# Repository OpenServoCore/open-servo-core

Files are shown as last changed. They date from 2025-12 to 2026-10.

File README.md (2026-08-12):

<p align="center">
  <picture>
    <source media="(prefers-color-scheme: dark)" srcset="docs/logo-dark.svg">
    OpenServoCore logo
  </picture>
</p>

# OpenServoCore

> An open platform for turning cheap servos into smart actuators.

OpenServoCore (OSC) is open hardware and firmware that drops a CH32V006 control board into a $2-3 cloned hobby servo (SG90 and friends) and turns it into a Dynamixel-class smart actuator with position feedback, current sensing, bus addressing, and programmability. The bus speaks the **osc-native protocol**, a break-framed wire protocol designed to run whole on sub-$0.20 MCUs ([design writeup](https://aaronqian.com/log/2026-08-08-servo-protocol-stream-processing/)).

The thesis is the price point. At mass-production volume, an OSC swap board should add **no more than ~$1 to the BOM** of a cloned servo. That is cheap enough that upgrading every servo in a robot to smart becomes the default instead of a premium decision.

If you are here for a board, jump to [Boards](#boards). The firmware and its progress are in [Firmware](#firmware), and the design writeups are in [Reading](#reading).

## Status

**In active development. Nothing here is shippable yet.** What exists today:

- The **OSC Dev CH32** dev board is validated (Rev B) and you can order one.
- The firmware's protocol and bus transport are implemented and bench-proven on real silicon. Control loops are next.
- **[tinyboot](https://github.com/OpenServoCore/tinyboot)**, the OSC bootloader, has shipped v0.4.0 as its own repo.

The servo swap board (the one that goes inside a servo) is designed but not spun yet.

## Boards

**OSC Dev CH32** (`hardware/boards/osc-dev-v006/`) is the firmware development platform. It accepts any gutted hobby servo, takes power from USB-C, 1S-2S LiPo, or a WCH-LinkE, and fans out every rail and signal to edge test points. Rev B is validated. The [board README](hardware/boards/osc-dev-v006/README.md) has full schematics, pinouts, jumper behaviour, and bringup notes.

Want one? The full KiCad design files live in `hardware/boards/osc-dev-v006/`, ready to send to the board house of your choice.

There is also an experimental BLDC variant (`osc-dev-m007`) in the tree. It is unvalidated, so don't fab it.

## Firmware

The firmware is written in Rust and lives in `firmware/`. It is organized as chip-agnostic library crates (protocol, drivers, control table, discrete-event integration tests), a CH32 chip crate, and board binaries. The chip-agnostic layers compile and unit-test on a desktop with no hardware attached, and a discrete-event simulation runs the production crates ([the architecture writeup](https://aaronqian.com/log/2026-08-01-chip-agnostic-architecture-bare-metal-rust/) covers how).

What works today is the osc-native protocol and the servo bus transport. On the bench that means 0.5-3 Mbaud multi-servo status chains, ~30 µs ping turnaround at 1 Mbaud, and hardware CRC in both directions. The register-table conventions (flat control table, staged writes, alert semantics) will feel familiar if you have used Dynamixel. Control loops, persistence, and safety features are in progress, and build instructions will appear as the firmware matures.

The bootloader, [tinyboot](https://github.com/OpenServoCore/tinyboot), is a separate repo. It is part of the OSC firmware stack but versioned and released independently, and it supports more chips than the OSC boards on purpose (V003 / V00x / V103).

## Reading

The deep-dive writeups live on the blog:

- **[Stream processing on the wire](https://aaronqian.com/log/2026-08-08-servo-protocol-stream-processing/)**: the osc-native protocol design, and how the servo replies in tens of microseconds on a $0.16 chip.
- **[A chip-agnostic architecture for bare-metal embedded Rust](https://aaronqian.com/log/2026-08-01-chip-agnostic-architecture-bare-metal-rust/)**: the full firmware architecture, layer by layer, with code.
- **[Using the SPI peripheral as a DMA-fed CRC engine](https://aaronqian.com/log/2026-07-25-spi-as-dma-crc-engine/)**: hardware CRC on a chip with no CRC peripheral.
- **[HSI trim: calibrating a crystalless MCU over the bus](https://aaronqian.com/log/2026-07-18-hsi-trim-crystalless-mcu/)**: fleet clock calibration with nothing but the bus wire.
- **[Dynamixel 2.0 servo side: RX timing](https://aaronqian.com/log/2026-07-04-dynamixel-servo-side-rx-timing/)** and **[Fast Sync/Bulk Read](https://aaronqian.com/log/2026-07-11-dynamixel-servo-side-fast-sync-bulk-read/)**: the reference pair if you are building a Dynamixel-compatible device.

There is also one design doc in the repo worth reading. [Control theory](docs/control-theory.md) lays out the control design for the servo, with the cascaded loops, the estimators, and the sensing tiers. It is the plan, written ahead of the implementation, and it is not implemented yet.

## AI Use

I use AI heavily in this project. Claude (Fable 5, Opus 5, and earlier models) does a lot of the code generation and most of the document drafting, including parts of this README.

That does not make this vibe-coded. I review every line before it lands, and the result has to survive checks that don't care how the code was written. CI builds and tests every crate and cross-builds every board image. A discrete-event simulation runs the production crates and caught over a dozen real bugs before they reached silicon. The transport numbers above were measured on the bench. And this project was not built in one prompt. The history spans multiple years and many revisions of both the hardware and the firmware.

The documentation is more uneven than the code, and even this README could be easier to consume. That will improve, but working firmware comes first.

## Contributing

This is early. The most useful thing right now is **following along and asking questions** rather than opening PRs.

- **Discussions:** [github.com/OpenServoCore/open-servo-core/discussions](https://github.com/OpenServoCore/open-servo-core/discussions) is where design questions, ideas, and "is this on the roadmap?" go.
- **Build journey:** posts at [aaronqian.com](https://aaronqian.com) document the design decisions, dead ends, and what shipped each week.
- **Issues:** open ones are scoped to specific work. For now, contributor scope is small.

## License

OSC is fully open source.

- **Firmware**: [MIT](LICENSE-MIT) **OR** [Apache-2.0](LICENSE-APACHE), at your option (Rust ecosystem convention).
- **Hardware** (schematics, layouts, board files): [CERN-OHL-P v2.0](LICENSE-HARDWARE).

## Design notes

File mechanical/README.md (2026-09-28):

# mechanical

Parametric CAD for OSC mechanical parts, written in
[build123d](https://github.com/gumyr/build123d) (Python, OCCT kernel).
One folder per project; each project writes its printable outputs
(STEP/STL/SVG/preview PNGs) to its own `build/` (gitignored).

- `sg90/` - SG90 servo modeling: motor, gears, pot, case, light fence.
  Measurements go into `sg90/measurements.py` with provenance; geometry
  is derived from them. One part per module; `build()` returns the
  solid.
- `mg90/` - MG90 clone facts, no geometry yet: `mg90/measurements.py`
  holds the counted gear train with the same provenance tags.
- `encbench/` - bench encoder rig for the ITR1204 coupon
  (hardware/boards/encoder-board): base, sled, clamp, discs, shims,
  paper patterns. Parametric over motor dims (imports
  `sg90.measurements`) and quadrature-phase presets.
- `carrier/` - tier-2 encoder carrier: printed pot replacement (stator
  body with coupon shelf + magnet cup rotor) around purchased 1.4mm rod
  and brass tube stock; imports `sg90.measurements`, dims pending the
  donor measurement session.
- `stenciljig/` - solder-paste stencil jig, build123d implementation
  of the mechanism from bobstay's parametric jig
  (printables.com/model/1209372, credited with thanks). Heat-set
  inserts swapped for captive M3 nuts, plate screws top-driven via
  under-base nut bars. One part per file, shared spec in
  `common.py`, mating cavities offset from the owning part's
  profile; every part exports pre-oriented and support-free (all
  internal ceilings are 45-degree tents, hoppers or cones). Two
  stacking parts: the jig stands on screw-on feet next to an open
  tote (`box.py`) standing on four of the same feet, holding the
  thickness adapters, low-profile standing-wedge squeegees, stencil
  sheets and spares; for transport the jig stacks onto the box as
  its lid - the rear feet's hook noses latch the box wall and two
  printed quarter-turn cam knobs seat under the box's descending
  ceiling tents to draw it down tight, no hardware in the joint.
  TPU desk pads snap into the feet's through bores (one pad and one
  foot model everywhere).
- `render.py` - shared headless STL preview.

## Setup

```sh
python3 -m venv .venv
.venv/bin/pip install -r requirements.txt
```

## Build

Run from `mechanical/`:

```sh
.venv/bin/python -m sg90.motor    # one part -> sg90/build/
.venv/bin/python -m encbench      # all rig parts -> encbench/build/
.venv/bin/python -m render sg90/build/sg90_motor.stl   # preview PNG
```

Stable STEPs consumed by KiCad get copied to `hardware/shared.3dshapes/`
deliberately, not by the build.

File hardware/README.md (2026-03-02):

# KiCad Component Management

## Component Linkage System

### Directory Structure

```
hardware/
├── shared.kicad_sym        # Symbol library
├── shared.pretty/           # Footprint library
├── shared.3dshapes/         # 3D models
├── templates/jlc4l_1v6mm/   # Template project (canonical reference)
└── boards/*/                # Board projects
```

### Linkage Patterns

#### 1. Project → Libraries

Projects link to shared libraries via `sym-lib-table` and `fp-lib-table`:

- Symbol library: `${KIPRJMOD}/../../shared.kicad_sym`
- Footprint library: `${KIPRJMOD}/../../shared.pretty`

#### 2. Symbol → Footprint

Symbols in `shared.kicad_sym` reference footprints using library prefix:

- Format: `"shared:FOOTPRINT_NAME"`
- Example: `"shared:UQFN-20_L3.0-W3.0-P0.40-BL-EP1.7"`

#### 3. Footprint → 3D Model

Footprints in `shared.pretty/` reference 3D models using relative paths:

- Format: `${KIPRJMOD}/../../shared.3dshapes/MODEL_NAME.wrl`
- Example: `${KIPRJMOD}/../../shared.3dshapes/UQFN-20_L3.0-W3.0-P0.40-BL-EP1.7.wrl`

## Component Acquisition Strategy

1. Navigate to a board or template directory:

   ```bash
   cd hardware/templates/jlc4l_1v6mm
   ```

2. Download component:

   ```bash
   easyeda2kicad --full --lcsc_id <LCSC_ID> --output ../../shared --overwrite --project-relative
   ```

3. Fix 3D model paths in footprint files:
   - Find: `${KIPRJMOD}././shared.3dshapes`
   - Replace: `${KIPRJMOD}/../../shared.3dshapes`

4. In `shared.kicad_sym`, rename the `LCSC Part` property to `LCSC` on the downloaded symbol.

## Post-Import Checklist

- [ ] Symbol has correct footprint reference (`"shared:FOOTPRINT_NAME"`)
- [ ] Footprint has correct 3D model path (`${KIPRJMOD}/../../shared.3dshapes/...`)
- [ ] Pin types are correctly set: power_in (VCC/GND), input (control/data in), output (data out), passive (connectors) - NO "unspecified" pins allowed
- [ ] 3D model displays correctly in KiCad 3D viewer
- [ ] Symbol uses `LCSC` property (not `LCSC Part`) for the part number
- [ ] Component source documented (LCSC part number)

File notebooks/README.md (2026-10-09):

# notebooks

This folder is where I look at real data from the servo rig. The firmware
streams raw ADC samples at the full 20 kHz control rate, the captures get
checked in under `telemetry/`, and the notebooks load them, plot them, and
check the control math against what the hardware actually did.

These notebooks are for understanding and for writeups, not for CI. They are
committed with their outputs baked in, so they read as documentation straight
from GitHub.

## Setup

You will need [uv](https://docs.astral.sh/uv/). Then:

```
cd notebooks
uv sync
uv run jupyter lab
```

`uv sync` creates a `.venv` and installs numpy, scipy, pandas, matplotlib, and
jupyterlab. Python is pinned to 3.12 in `.python-version`, and uv will fetch it
for you if you don't have it.

`uv run pytest` runs the tests under `tests/`, which check the parts of
`oscnb` that can be checked offline against data with a known answer.

## Telemetry

The captures live under `telemetry/`, one folder per dataset (one servo or
static load, on one board, on one supply), then one folder per experiment, then
one folder per capture:

```
telemetry/
  sg90-a__dev-v006-D__2s/
    dataset.toml
    grid/
      capture-1/
        meta.json
        sweep.csv.gz
```

Every recording is raw ADC counts straight off the wire, with a per-sample
tick counter, so missing samples are provable from the data itself. The
constants that turn counts into volts and amps live in `oscnb/boards.py` (the
measurement chain) and `oscnb/servos.py` (the thing measured). Each
recording's `meta.json` carries the board's parts in a `sense` block, and the
loader picks the board from it and refuses a capture that does not match.

## The notebooks

Each notebook states what it measures, how, and what is still open at its end.
01 to 08 read an SG90 on board D, the hand-reworked development board before
rev 2A; 09 reads an MG90 on board D; 10 on read rev 2A, with board D alongside
where a comparison needs it.

- `01-bridge-states`: what each ADC sample means in each H-bridge state and
  decay mode, and when it is valid.
- `02-electrical`: winding resistance and brush drop as a two-parameter line,
  the winding inductance, and the burst fit's R-V0 ridge.
- `03-back-emf`: the back-EMF constant by three routes, and ripple speed plus
  coast back-EMF as a speed that needs no pot.
- `04-friction`: Coulomb and viscous friction from coast deceleration and
  steady current, and breakaway.
- `05-inertia`: rotor inertia from the rise curve, cross-checked by coast.
- `06-gear-train`: the ripple tachometer, motor angle against the pot, gear
  play and slip signatures.
- `08-velocity-observer`: rest noise per channel and its structure, then
  back-EMF, pot derivative and ripple as speed estimates, and how the observer
  combines them.
- `09-pot-linearization`: the ripple-referenced position table and degrees
  from counted teeth.
- `10-sense-chain-boards`: capture integrity, and the sense chain graded
  against a meter on a resistor grid, board against board. Then the current
  reading on rev 2A's final amplifier network, on a stalled MG90 and a 15.3 ohm
  resistor, and the settle gain it needs.
- `11-back-emf-on-rev-2a`: the low-duty back-EMF over-read, re-scored on rev 2A.
- `12-pot-table-free-vs-governed`: how far the position table moves between
  sessions, against its own split-half floor.
- `13-output-angle-from-video`: output angle from a camera, proven on rendered
  frames.
- `15-op-amp-over-board-temperature`: current amplifier gain and zero against
  board temperature.
- `16-duty-floor-in-the-tap-sample-timing`: where each tap samples inside a
  short drive window, and the duty floors that follow.
- `17-winding-thermometer-calibrated`: copper's temperature coefficient
  confirmed on the MG90 with a DC meter pair.
- `18-two-node-thermal-model`: the winding and can as two thermal nodes.
- `19-shipped-winding-thermometer`: the NTC-based winding thermometer as
  shipped, graded against a K bead on the can across torque-off gaps, with
  the bridged-segment event, the guards and the boot prior. Dataset
  `mg90-a__dev-v006-2A__dps__thermometer`; loader `oscnb.thermometer`.
- `20-bare-motor` measures the MG90's motor out of the servo, on a plate with
  no gearbox or load: rest resistance across rotor stops, no-load current,
  the back-EMF constant by the coast route, why the duty ramp cannot measure
  the inductance, the resistance in rotation, and breakaway. Dataset
  `mg90-a__dev-v006-2A__dps__bare-motor`; loaders `oscnb.staticsweep` and
  `oscnb.meterlog`.

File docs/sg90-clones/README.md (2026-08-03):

# SG90 clone database

"SG90" is a shape, not a spec. Every brand - clones and genuine TowerPro
alike - ships its own internals behind the same case. Mechanically the
cases, pots, and layouts are near-identical across brands; what actually
differs, and what matters for drive electronics and reliability, is the
**gear train** and the **motor**. This folder records exactly those two
things per brand, one file per servo model, so brands can be compared
before committing a fleet to one.

Each entry records:

- Gear train: tooth counts per stage, overall ratio, modules, materials,
  and any observed failure pattern (which gear strips, under what load).
- Motor: can dimensions and family, shaft/boss geometry, terminal
  arrangement, rotor construction, and electrical characteristics as
  they get measured.

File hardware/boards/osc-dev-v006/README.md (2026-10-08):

# OSC Dev V006 - Rev. 2A

> **Built and brought up.**
> Rev. 2A board #1 runs an MG90 on 2S. Position calibration, the position table, motor identification and closed-loop verify all pass on it, and the sense chain is graded in [Measured on board #1](#measured-on-board-1).
> Not exercised yet: the encoder inputs (J6 / J11), Qwiic, and the second position channel. Rev. 2A also stays open for value changes that need no routing change, so the BOM can still move; see [Still open](#still-open).
> **Fabricate this at your own risk!**

See [CHANGELOG.md](CHANGELOG.md) for revision history.

This is the OpenServoCore firmware development and validation board. It is built around the CH32V006F8P6 and designed to accept any gutted hobby servo (SG90, MG90, and similar), so firmware can be brought up and characterized against real motor / pot / encoder hardware.

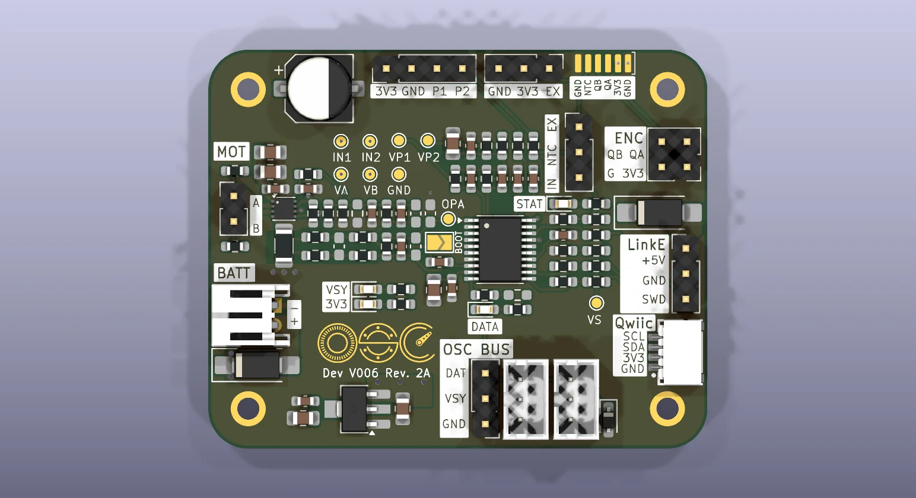
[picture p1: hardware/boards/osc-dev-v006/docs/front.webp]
Front


KiCad render of Rev. 2A.

## Overview

- **MCU** - CH32V006F8P6 (RISC-V, 48 MHz, 62 KB flash, 8 KB RAM, TSSOP20). Every pin is used, including the reset pin.
- **Motor driver** - TI DRV8212PDSGR (U3). H-bridge with IN1/IN2 PWM. 4 A peak, VM 1.65-11 V. Continuous current is thermally limited on this layout to about 1.4 A at room temperature; the exposed pad sits on the top-only `PGND` island and dumps heat through the prepreg into the ground plane, not into a copper plane of its own.
- **Current sense** - 60 mOhm kelvin-connected low-side shunt (Rs1) feeding the MCU's on-chip op-amp in bare mode. An external four-resistor difference network sets G = 14.88 against a 1.10 V bias, so both current directions are visible.
- **LDO** - HT7533-1 (U1) for the 3.3 V logic rail. No thermal shutdown, and its 500 mW budget at 2S caps the `+3V3` load at about 55 mA, board included, so keep add-ons on the 3V3 pins light and mind probe slips on the 3V3 headers. The DRV8212P VCC (`+3V3_DRV`) hangs off the same `+3V3` as the MCU through Rh2, a fitted 0R that a ferrite can replace.
- **Servo bus** - single-wire half-duplex UART on `PC0`, wired straight to the MCU through a 33 Ohm series resistor. No buffer, no TX_EN. Direction turnaround and RX timing are firmware's job.
- **Telemetry** - no dedicated pin. Telemetry rides the `DATA` wire as bounded CRC'd bursts, so there is no second UART on the board.
- **Qwiic** - SH 1.0 mm 4P I2C connector (J3) for an encoder module, either magnetic (I2C) or a quadrature encoder breakout.
- **Power input** - 1S-2S LiPo (3.0-8.4 V) via JST-PH, or the WCH-LinkE 5 V rail. Either or both, OR'd through SS54 Schottkys (about 0.25 V drop).
- **Debug** - WCH-LinkE over the CH32V006 1-wire SWDIO, on a 1x03 header (J2).
- **Position feedback** - potentiometer or analog magnetic encoder on J5, I2C encoder on J3, or an ADC-sampled IR encoder on J6 (pins) or J11 (flex landing).
- **Supply and terminal sense** - `VSYS` measured directly through its own divider, plus both motor terminals referenced to a common bias so back-EMF is readable while the bridge coasts.
- **Temperature** - onboard NTC (TH1) or external NTC (J7), selected with JP2.
- **Board** - 50 x 40 mm, 6-layer 1.6 mm (JLCPCB JLC06161H-3313 stackup), ENIG, via-in-pad.

### Changed from Rev. B

Rev. 2A is a big respin. Here is what changed:

- The 74LVC2G241 UART buffer is deleted. The bus `DATA` line connects straight to the MCU through a 33 Ohm series resistor (Rx1), and RX timing moved fully into firmware.
- Current sense is reworked around the CH32V006's on-chip op-amp: kelvin shunt, external difference network, and a VREF bias for bidirectional current.
- Motor terminal sense divider bottoms return to a bias node (`VB`) instead of GND, so both terminals stay readable during coast.
- `VSNS` is back, on its own pin, as a direct divider off `VSYS`.
- USB-C and screw-terminal power inputs are dropped. Battery and LinkE 5 V remain.
- The PWM servo header is dropped. Qwiic (I2C) is added.
- The edge test-point hook rails are replaced by nine 1.0 mm probe pads, most of them in two rows next to the sense network. See [Test points](#test-points--probing).
- 4 layers to 6 layers, and all connectors are renumbered.

## MCU pinout

CH32V006F8P6, TSSOP20. The "Function used" column is what the board wires the pin for.

|Pin|Port|Net|Function used|
|---|---|---|---|
|1|`PD4`|`OPA_OUT`|Op-amp output (`OPO0`). The same pin is ADC `A7`, which samples it.|
|2|`PD5`|`VSNA`|ADC `A5`, motor terminal A sense.|
|3|`PD6`|`VSNB`|ADC `A6`, motor terminal B sense.|
|4|`PD7`|`RST`|`nRST` from the factory. After the option byte flip it becomes the op-amp `+` input (`OPP1`) through JP1. See [First boot](#first-boot).|
|5|`PA1`|`VPOS1`|ADC `A1`, position channel 1: pot wiper or the first transducer output (RC-filtered).|
|6|`PA2`|`VPOS2_NTC`|ADC `A0`, position channel 2 for a dual-transducer sensor, or the NTC divider when JP2 is jumped.|
|7|-|`GND`|`VSS`.|
|8|`PD0`|`OPA_N`|Op-amp `-` input (`OPN1`), difference network summing node.|
|9|-|`+3V3`|`VDD`.|
|10|`PC0`|`DATA`|USART1 TX (remap 3), half-duplex (HDSEL) servo bus. Also TIM2 CH1 (remap 4) as the input of the bus break wake.|
|11|`PC1`|`SDA`|I2C1 SDA, Qwiic (J3).|
|12|`PC2`|`SCL`|I2C1 SCL, Qwiic (J3).|
|13|`PC3`|`DRV_EN`|GPIO to the DRV8212P nSLEEP. A 10K pulldown (Rh1) keeps the driver asleep at reset.|
|14|`PC4`|`VSNS`|ADC `A2`, `VSYS` supply divider.|
|15|`PC5`|`DRV_IN2`|TIM1 CH2 (remap 8), H-bridge PWM.|
|16|`PC6`|`DRV_IN1`|TIM1 CH3 (remap 8), H-bridge PWM.|
|17|`PC7`|`STAT`|STAT LED, active low, driven as a plain GPIO. The only firmware-driven lamp.|
|18|`PD1`|`SWDIO`|1-wire debug, 100 Ohm series (Ru1) to J2.|
|19|`PD2`|`ENCB`|Encoder B. ADC `A3`, analog quadrature sampling.|
|20|`PD3`|`ENCA`|Encoder A. ADC `A4`, analog quadrature sampling.|

TIM1 runs center-aligned PWM on IN1/IN2 at 20 kHz, and its update event triggers the ADC scans at the counter crest and trough (see [PWM and ADC timing](#pwm-and-adc-timing)). Remap 8 puts TIM1 CH4 on `PC7`, but CH4 is unused and STAT is a GPIO.

## Connectors

All 2.54 mm pin headers are vertical through-hole.

### Battery - J1

JST-PH 2P horizontal. **1S-2S LiPo only (3.0-8.4 V).** The DRV8212P caps the safe motor rail at 11 V, so 3S is not supported. This input is OR'd into `VSYS` through an SS54 (Dp1), so it coexists with LinkE power.

### WCH-LinkE - J2

1x03 pin header (2.54 mm) for the WCH-LinkE programmer / debugger.

|Pin|Net|Notes|
|---|---|---|
|1|`VPROG`|LinkE 5 V rail, OR'd into `VSYS` through an SS54 (Dp2).|
|2|`GND`||
|3|`SWDIO`|1-wire debug, through a 100 Ohm series resistor (Ru1).|

Three pins is the whole header now. Telemetry rides the servo bus, so the LinkE's TX / RX are not connected to anything.

Plugging in the LinkE alone is enough to power the board. Very handy for firmware-only sessions.

### Qwiic - J3

SH 1.0 mm 4P (GND / +3V3 / SDA / SCL), standard [Qwiic](https://www.sparkfun.com/qwiic) pinout. 4K7 pull-ups (Rq1 / Rq2) sit on the MCU side, and 100 Ohm series resistors (Rq3 / Rq4) sit between the MCU and the connector.

This one is meant for an encoder module rather than generic sensors: an I2C magnetic encoder (MT6701 / AS5600 breakout) or a quadrature encoder adapter. The board has no hardware quadrature counting (see J6), so Qwiic is the flexible stand-in for it. I2C1 is polled.

### Motor - J4

1x02 pin header carrying `MOT_A` / `MOT_B` straight off the DRV8212P outputs. Through-hole, so the high-current path stays zero-via.

### Position - J5

1x04 pin header, `+3V3` / `GND` / `POS1` / `POS2`. It takes:

- The gutted servo's **potentiometer** on `POS1`. Excitation comes from `+3V3` and the wiper goes into `POS1`. Excitation and ADC reference share the same rail, so the reading is ratiometric and supply drift cancels out.
- An **analog-output magnetic encoder** (e.g. MT6701 in ratiometric analog mode) as a drop-in pot replacement on the same first three pins.
- A **dual-output transducer** (sin / cos style, the tier-2 sensor) on `POS1` and `POS2`. `POS2` shares its ADC pin with the NTC, so leave JP2 open in this mode; the on-board temperature reading is given up for the second channel. Both channels sit behind identical 4K7 / 100nF filters (Ra1 / Ca1 and Ra2 / Ca2) so the pair stays phase-matched.

With a pot or a single-output encoder, leave `POS2` unconnected and jump JP2 for the NTC. For a digital magnetic encoder use Qwiic (I2C) instead.

### Encoder - J6

2x02 pin header. `+3V3` / `GND` on one row, `ENCA` / `ENCB` on the other, going into ADC channels `A4` / `A3`. Silk reads `QA` / `QB` for the two phases.

This is a future expansion connector for an ADC-sampled custom IR quadrature encoder, in the style of [ServoProject](https://github.com/adamb314/ServoProject). The analog A/B phases get oversampled and interpolated for sub-count resolution. Hardware quadrature counting is not possible here since `PD2` / `PD3` don't carry TIM2 CH1/CH2, so I never considered it. A digital encoder belongs on Qwiic instead.

### Motor encoder flex - J11

Six bare pads at 1.0 mm pitch for the motor-shaft encoder flex, attached tin-and-iron: the flex fingers are pre-tinned, laid on the pads and pressed with an iron, then hot glue over the pad row takes the strain. The footprint pair (`Flex_Landing_1x06_P1.0mm` on the board, `Flex_Fingers_1x06_P1.0mm` on the flex) lives in the shared library, and the same landing goes on the swap board, so the dev board rehearses the real attach. Pin 1 is at the bracket mark.

|Pin|Net|Notes|
|---|---|---|
|1|`GND`|Outer ground, guards the pair.|
|2|`+3V3`|Emitter and phototransistor supply.|
|3|`ENCA`|IR sensor A, ADC `A4`. Same net as J6. Silk `QA`.|
|4|`ENCB`|IR sensor B, ADC `A3`. Same net as J6. Silk `QB`.|
|5|`VNTC_EXT`|Thermistor on the motor can, into the external leg of JP2. The divider resistor sits on the flex. Silk `NTC`.|
|6|`GND`|Outer ground.|

J6 and J11 are the same encoder input in two shapes: pins for a wired breakout or the bench coupon, the landing for the flex. Populate one.

### External NTC - J7

1x03 pin header, `VNTC_EXT` / `+3V3` / `GND`, for an external NTC thermistor or temperature sensor. Select it with JP2. The `+3V3` pin is there so the external part can bring its own pull-up or supply: a bare thermistor divides against a resistor on the connector, a sensor with a driven output just takes the rail. Rn1 10K serves the internal TH1 leg only, so nothing on the board loads the external node. The firmware's NTC constants (10K pull-up, 10K / 3950 part) describe the onboard divider, so a bare 10K / 3950 thermistor on J7 takes the same conversion when a 10K from the J7 `+3V3` pin to `VNTC_EXT` divides against it.

### Servo TTL bus - J8 / J9 / J10

OpenServoCore talks over a single-wire half-duplex UART, the same electrical layer as a TTL servo bus. Three wires only (`GND` / `V+` / `DATA`), the same pin count as a hobby servo cable. The wire protocol on top is **osc-native**, OSC's own break-framed protocol built for sub-$0.20 MCUs ([spec](../../../docs/osc-native-protocol.md)).

Three connectors share the same nets. Pick whichever fits your wiring:

- **J8** - 1x03 pin header for breadboard / daisy-chain wiring.
- **J9, J10** - JST-PH 3P vertical for cables.

Pin order is `G` / `V` / `D` with `V` in the center, so a reversed bench header only swaps `DATA` and `GND`, never power.

The powered board feeds `VSYS` onto `V+` to power downstream boards over the same cable. On the `DATA` line the order is connector, then ESD clamp (Dx1, PESD5V0L1BA), then the 33 Ohm series resistor (Rx1), then the pin. Rx1 is 33 Ohm rather than the usual 100 Ohm because `DATA` is the one line where edge speed matters at 3 Mbps over a whole chain, and the clamp does the protection work.

Rx2 is a DNP 10K pull-up footprint. The bus wants exactly one pull-up, at the host end, and servos self-bias internally, so populate Rx2 only when this board is the end of the wire on the bench. Board #1 runs with Rx2 fitted, on an osc adapter cable that carries `DATA` and `GND` only.

**`V+` is `VSYS` directly, unprotected.** Anything you daisy-chain to the bus must tolerate the upstream board's full input voltage (up to 8.4 V at 2S full charge).

## Jumpers

### Bootstrap - JP1 (solder jumper)

This jumper bridges the op-amp `+` input network (`OPA_P`) onto the shared `nRST` / `OPP1` pin (`PD7`). It ships open on fresh boards and gets closed as the last step of [first boot](#first-boot). Current sense is inactive until it is closed.

### NTC source select - JP2

1x03 pin header, silk `EX` / `NTC` / `IN`. The center pin is the common signal routed to ADC `A0` through Ra2 / Ca2. Jump it to either side, or leave it open:

- `NTC` to `IN` uses the onboard Rn1 / TH1 divider.
- `EX` to `NTC` uses the external thermistor on J7.
- Open: the pin is position channel 2 (`POS2` on J5) and there is no temperature reading.

## Current sense

Motor return current flows through Rs1 (60 mOhm, 1 %, 50 ppm, 1206) between `PGND` and `GND`. Rs1 is the only tie between the two grounds, so every amp of motor return has to cross it. Net-tie kelvin taps (NT1 on the `PGND` pad, NT2 on the `GND` pad) feed the MCU's on-chip op-amp, which runs in bare mode behind an external four-resistor difference network.

- **Gain.** Rf 6K4 / Rg 430 gives G = 14.88. With the 60 mOhm shunt that is 893 mV/A at the ADC, about 0.9 mA per LSB.
- **Bias.** The amplifier references `VREF` = 1.10 V (Rd1 1K6 from `+3V3` over Rd2 1K6 in parallel with Rd3 1K6, decoupled by Cd1), so negative current from regen or reversal is visible too. The usable range is roughly -1.2 A to +2.3 A by design, the top set by the amplifier's output ceiling near VDD - 0.16 V. On board #1 the rest output sits about 0.15 V under `VREF`, the op-amp's input offset times its noise gain and inside the part's spec, which moves the range to about -1.1 A to +2.4 A. The offset drifts with board temperature (see [Measured on board #1](#measured-on-board-1)), so firmware measures the rest at boot and keeps tracking it whenever the shunt carries no current: torque off, a brake or coast, and the brake half of a slow-decay drive. The KiCad schematic lists Rd2 300 with Rd3 unfitted, a 0.52 V `VREF` and a -0.58 A to +2.9 A range; board #1 is built with 1K6 in both.
- **Compensation.** Cc1 / Cc2, 22 pF across each feedback arm, for a corner around 1.1 MHz.
- **Input filter.** Ci1, 100 pF across `OPA_P` / `OPA_N`.

Rk1 / Rk2 (fitted 0R) sit in series with the kelvin taps. They are swap points for gain-trim experiments: if they ever become real resistors, swap both to the same thin-film value or the arms go out of balance.

Precision money goes to the shunt (1 %, 50 ppm) and the Rf / Rg quad (0.5 %, 25 ppm thin film). Matching and drift are what limit accuracy there and firmware cannot compensate for either. Everything downstream is offset error and boot calibration eats it.

This is a swap-and-measure board, so the populated values are a starting point and a set of experiment footprints ship unpopulated (DNP):

|Ref|Value|Purpose when fitted|
|---|---|---|
|`Cc3` / `Cc4`|22 pF|Stack on the 22 pF comp caps for a slower, quieter corner (about 570 kHz).|
|`Ck1`|100 pF|Differential filter across the kelvin pair, ahead of the gain resistors.|
|`Co1`|22 pF|Load cap on the op-amp output. Layout insurance. `PD4` is both the op-amp output and the ADC pin, so the cap sits straight on the output; keep it under the 50 pF load limit.|
|`Rx2`|10K|`DATA` bus pull-up for single-device bench setups.|

The shunt itself has no alternate footprint. Other values (22 to 150 mOhm, all 1206) swap onto Rs1's own pads, so the kelvin taps never move. A second shunt in parallel would split the current by pad and trace resistance and break the symmetric entry, so there is no pad for one.

The DRV8212P's own OCP / TSD is the first protection layer. OCP trips at 4 A minimum, above the 2.3 A where the sense chain saturates and the 2.2 A firmware overcurrent trip under it, and a hobby motor stalls below it, so a hard stall lands on TSD first and the driver hiccups at about 1 Hz until firmware drops `DRV_EN`. OCP only fires on a shorted lead pair, in 4 us pulses the ADC will not see. V006 has no comparator units, so the rest is firmware: a kernel I2t limit drops `DRV_EN` and latches a stall fault that only the user can clear, IWDG covers hung firmware, and any reset kills the bridge through the Rh1 pulldown.

## Other sensing

### Motor terminal voltage

`MOT_A` / `MOT_B` go through Rv1 / Rv3 (6K4) into ADC `A5` / `A6`, with Rv2 / Rv4 (1K6) and Cv1 / Cv2 (100 pF) returning to `VB` instead of `GND`.

`VB` is a 0.623 V bias node (Rb1 430 / Rb2 100 from `+3V3`, bulk Cb1 10uF and Cb2 100nF). The divider ratio is 0.20, so a tap reads `0.2 x terminal + 0.8 x VB`:

- A 2S rail at 8.4 V taps about 2.18 V, well inside the ADC range.
- During coast, the free terminal sits a diode below `PGND` or a diode above `VSYS`. At -0.9 V the tap is still 0.32 V, and at 9.3 V it is 2.36 V, so neither phase clips.

That is the point of the bias: both terminals stay readable while the bridge coasts, so `vA - vB` is real back-EMF rather than a rail-clamped stub. The rail comes back as `5 x tap - 4 x VB`.

`VB` is read at boot with the driver parked. With the bridge Hi-Z no current flows in either leg, so both taps sit at `VB` itself and firmware recovers the bias with no extra pin. If the two taps disagree by more than 64 counts, the 773-count nominal stands in. The bias also shifts with drive current, since the divider bottoms inject into the `VB` node against its own 81 Ohm source impedance: about +80 mV at full duty on a 2S rail, which the 0.20 ratio turns into 0.3 V on a single-terminal reading. Firmware keeps the boot value and does not track that shift. The back-EMF path reads `vA - vB`, which is immune, and since both terminals are measured, a host that needs one terminal's absolute voltage under drive can correct `VB` from the two taps with one multiply-add.

Cv1 / Cv2 have one open option: 100 nF in place of 100 pF turns the taps into averaging taps, which would let the terminal read below the 160-tick floor (see [Terminal voltage and back-EMF](#terminal-voltage-and-back-emf)). The firmware would need an estimator that weights the crest and trough terminal samples by their ticks, and every consumer that reads the terminal at the PWM edge loses that view. Not decided; board #1 carries 100 pF.

### Supply voltage

`VSYS` has its own divider straight to `GND`: Rv5 6K4 / Rv6 1K6 with Cv3 100 pF, into ADC `A2`. Divide by 5, so 8.4 V lands at 1.68 V. Same reels and the same phase as the terminal dividers, so the two chains track each other and rail minus terminal resolves the bridge drop instead of disappearing into a ratio disagreement.

### Position

Two channels with the same filter. `POS1` goes through Ra1 4K7 and Ca1 100nF into ADC `A1`. `POS2` goes through Ra2 4K7 and Ca2 100nF into ADC `A0`, the node JP2 also drives, so it is either the second transducer output or the NTC, never both.

### Temperature

Rn1 10K pulls up against the onboard 10K / 3950 TH1 on the internal leg of JP2. JP2 routes that divider (or the external thermistor on J7) onto the shared `A0` node, where Ca2 100nF is the filter for every source; Ra2 is only in the `POS2` path.

## Measured on board #1

Rev. 2A board #1 on a 2S LiPo, first against a 3.7 Ohm resistor grid (4.4 Ohm at J4 with its cable), then with an MG90 fitted. The grid figures come from [notebook 10](../../../notebooks/10-sense-chain-boards.ipynb), which grades the chain against board D (the bodged Rev. B rig), and the back-EMF figures from [notebook 11](../../../notebooks/11-back-emf-on-rev-2a.ipynb). The constants a capture is read with live in the `dev-v006-2A` entry of [`notebooks/oscnb/boards.py`](../../../notebooks/oscnb/boards.py), and the ones the servo runs with in the board's [`main.rs`](../../../firmware/boards/osc-dev-v006/app/src/main.rs). Those two are the authority; the tables below quote them. Source columns cite notebook sections as `nb10 sec 8`.

Ticks are 48 MHz TIM1 ticks (20.8 ns). The PWM half-period is 1200 ticks, so a drive window of `h` ticks is `h / 1200` duty.

### PWM and ADC timing

|Item|Value|Source|
|---|---|---|
|PWM|Center-aligned, ARR 1200 at 48 MHz, 2400 ticks a period: 20 kHz.|`servo-ch32/src/cfg/chip.rs`|
|ADC clock|24 MHz (HCLK / 2).|`servo-ch32/src/hal/clocks.rs`|
|Aperture|13.5 ADC clocks on every channel. A conversion is 26 clocks: 1.083 us, 52 ticks, 0.92 Msps.|`cfg/chip.rs`, nb10 sec 8|
|Trigger|TIM1 update (TRGO) at the counter crest and at the trough, so two scans a period. TIM1 CH4 (CCR4 = ARR - 68) starts the low-side tap's injected conversion before the crest: tap B forward, tap A reverse.|`control/sensors/scan.rs`|
|Scan order|shunt, high tap, low tap, pos, vcal, vbus, ntc: vmA before vmB forward, vmB before vmA reverse. The order follows a direction flip one period late.|`main.rs`, `control/sensors/scan.rs`|
|Sample closes from the crest|Low-side tap -37 (injected), shunt +31, high-side tap +83; the scan's own low-side tap +135, read only from the trough scan (Fast decay). The same in both directions. The ADC's 2-clock trigger delay included.|nb10 sec 8, bringup `captures/winding-r/injb`|

Under slow decay the drive window is centred on the crest, so the crest scan reads the driven half; under fast decay the trough scan does.

**Why 24 MHz, not 48.** With the ADC's low-power comparator buffer on, a bit trial at 48 MHz gets 20.8 ns and the buffer does not settle. A pot sweep on board D reported 63% of the codes the wiper crossed at 48 MHz against 96% at 24 MHz, with the 55 codes under 1024 unreachable. The aperture cannot shrink either: 3.5 and 7.5 clocks run a slot at 1.5 and 1.2 Msps, which datasheet Table 3-23 rates only from VDD 4.5 V, and the MCU rail here is 3.3 V.

### Current sense

|Quantity|Design|Board #1|Source|
|---|---|---|---|
|Scale|1108.5 counts/A, 0.902 mA per count|Amplifier and ADC +0.5% (-0.7 to +2.3%): 93-94 mV on a meter across Rs1 during a 100% grid lap, against 93.3-95.1 mV from the chip's current times 60 mOhm.|`boards.py` `current_chain_scale_measured`, nb10 sec 7|
|Rest output|1.10 V (`VREF`)|About 0.15 V under `VREF` torque off at room temperature: 0.37 V over the schematic's 0.52 V `VREF`. Offset, tracked by firmware.|board #1 bringup|
|Rest drift|-|Normal mode: 1178 counts at 28 C, 1174 at 44 C, 1170 at 60 C, about -0.25 counts/C. High-speed mode, measured earlier over the 0.52 V `VREF`: 467 counts at 28 C, 398 at 43 C, 260 at 60 C. The on-chip op-amp has no drift spec.|board #1 bench|
|In-drive zero|-|10 counts over the torque-off rest: the DRV8212P's own supply current returns through Rs1 once the driver wakes.|nb11 sec 1|
|Rest noise|-|1.28 counts RMS (1.15 mA). Board D 1.7.|`rest_current_noise_measured`, nb10 sec 3|
|Step response|-|Half-way 48 ticks (1.00 us) after the ON compare, then a 13.1-tick (273 ns) exponential and a slow tail, 3.3% at half-way +48 ticks and 0.7% at +96. High-speed mode was 44 ticks, 10.1 ticks and 2.6%, with the same 0.7%. Steepest about 2.4 V/us.|bringup `captures/winding-r/c0` bursts, shunt over the terminal difference|
|Settled to 1%|-|156 ticks (3.25 us) after the ON compare, always approached from below. Measured in high-speed mode; normal mode's tail matches it within 0.1% from 130 ticks.|`shunt_settle_measured`|
|Crest honest to 3%|-|From 7% duty on the 2S grid. Board D 15%.|`crest_floor_measured`, nb10 sec 5|
|ON pulse against the command|DRV8212P dead time 500 ns (24 ticks) typ|30 ticks short at half height on the grid. On the MG90, 10-15 ticks short at about 0.1 A and 20-25 at 0.2 A and up.|nb10 sec 8.1, nb11 sec 4|

**Op-amp temperature.** The op-amp runs in its normal mode. High-speed mode is off in firmware with no switch to turn it on: it gives up the factory offset trim (WCH AN24000), and on board #1 that cost more than the bandwidth bought. Board #1 drove the 3.7 Ohm grid at four DC levels, 54 to 99 mV across Rs1 on a meter, at room (28 to 30 C board), 44 C and 60 C, then at room again, once per mode. The data is `captures/winding-r/c0` in the osc-dev-v006-bringup repo.

|Mode|Gain, room to 60 C|Zero, torque off|In-drive offset|
|---|---|---|---|
|Normal|-0.26%, back within 0.1% at room again|1178 to 1170 counts|About +10 counts, steady|
|High-speed|+0.8% at 44 C, +4.3% at 60 C|1106 to 916 counts|21 counts at room to 46 at 60 C, level-dependent|

High-speed mode bends above 43 C. In normal mode the meter reads 1110.9 counts/A through zero at room, +0.22% on the 1108.5 design. Counts per level fall 0.4% from 54 to 99 mV, which looks like compression but is the +10-count step between the torque-off zero and the in-drive zero (see In-drive zero above), spread over the levels by a fit through the torque-off zero. The winding-R ladder holds within 1% of its 30-40% reference from 15% duty and within 3% from 10%, in both modes at every temperature: tap B's sample timing sets that floor, not the op-amp. A firmware change to the tap sampling is in progress.

**Window floor.** The firmware reads a current only when the drive window is at least `i_window_min_ticks` wide. Uncorrected, the grid's crest sample reads low under every floor, never high. In normal mode, from the high-speed grid ladder (nb10 sec 8.2) times the measured ratio between the modes:

|Within|Window|Duty|
|---|---|---|
|1%|125 ticks|10.4%|
|2%|88 ticks|7.3%|
|3%|72 ticks|6.0%|
|5%|58 ticks|4.8%|

The board runs at 64 ticks (5.3% duty): a slightly low reading beats no reading. On top of that, `i_settle_gain` multiplies every window-valid current by the inverse of the step response at its sample instant, in 21 Q15 bands of 8 ticks from 40 ticks (x1.133) to 208, unity past that. In normal mode the grid ladder reads about 4.5% low at 60 ticks and 1.1% at 120, settled from about 208, the same in both drive signs. The table is the high-speed one, which put every grid rung from 60 to 300 ticks within 0.16%, times the ratio between the modes; that predicts every rung from 64 ticks within 0.5%. Telemetry's `current_raw` and `current_trough` and the bias tracker stay raw.

Two things the gain cannot remove:

- **The motor's edge spike.** The MG90 carries about 10 nF at its terminals, and the high side charges it through the shunt at every turn-on. Under about 72 ticks that reads a fixed few counts high, 10-15% of a 30-count current at the 64-tick floor. It is additive, so no gain removes it, and under about 48 ticks a stalled MG90 reads high overall.
- **The bias tracker's reach.** The in-drive zero is learned only from brake troughs of at least 960 ticks (`bias_brake_min_ticks`, up to 20% duty), because the amplifier's tail after a pulse holds a shorter trough above rest. That tail was measured on board D and carried over.

### Terminal voltage and back-EMF

|Quantity|Board #1|Source|
|---|---|---|
|Tap difference|4.028 mV at the terminals per count of `vA - vB` (r = 5), bias free.|`boards.py`|
|One terminal|`5 x tap - 4 x VB` in counts. A driven-low terminal reads 618 counts, not 0.|`boards.py` `term_v`, nb11|
|`VB` at rest|Taps 769.8 and 771.0 counts against 772.8 nominal (tap A 620 mV).|nb10 sec 3|
|`VB` under drive|With tap B disconnected from its terminal, it read the node itself: +68 mV (84 counts) at the forward 100% rung, against +67 mV from the 81 Ohm source.|nb10 sec 9|
|Tap A rest noise|0.86 counts, 3.5 mV at the terminal.|nb10 sec 3|
|Low-side path|0.218 Ohm on the A side: switch, shunt and copper.|nb10 sec 5.1|
|Window edge|The terminal starts to fall 8.5-9 ticks after the OFF compare. The high-side tap at +83 reads the window from about 74 ticks, the injected low-side tap from about 90, the trough scan's low-side tap from about 126.|nb10 sec 8.4, bringup `captures/winding-r/injb`|
|Coast EMF|1.24 mV per ripple Hz both ways on the MG90. Board D 1.21-1.23.|nb11 sec 3|
|Low-duty over-read|The 15% rung reads 3.0% (forward) and 3.6% (reverse) high against a `Ke` fitted on 25-30%. Board D 7.7-7.8% on the same motor.|nb11 sec 3|

`v_window_min_ticks` is 93 (7.7% duty). The low-side tap is sampled 37 ticks before the crest, so the floor is its rise after the ON edge: on the grid, forward drive reads R within 1.1% from 84 ticks, against 3.8% high at 96 when tap B sat in the scan's third slot. Reversed, with tap B sampled early as the high side, the same ladder read 3-5% high from 96 to 180 ticks against the 30-40% rungs: the early sample catches the high side's post-edge overshoot. So the taps swap with the drive direction, the low side always early and the high side always at +83, and the same ladder then reads R within 0.9% from 96 ticks in both directions. Fast decay keeps 160 (`v_trough_window_min_ticks`), its low-side tap still in the trough scan. The coast reading says the terminal chain reads the EMF as well as board D's; the low-duty over-read is the drive pulse coming out shorter than commanded, which a crest sample cannot see (11-16 ticks explains all of it on the MG90). The back-EMF observer keeps its own 160-tick floor (`bemf_window_min_ticks`) until it takes that shortfall off the commanded width; under it the back-EMF is void, which is why closed-loop verify's velocity legs, at 8-11% duty, run on the pot observer.

### Supply voltage

|Quantity|Board #1|Source|
|---|---|---|
|`VSNS` scale|Ratio 5 (Rv5 6K4 / Rv6 1K6 to `GND`): 4.028 mV at `VSYS` per count.|`main.rs`, `boards.py`|
|Pack voltage|`VSYS` + 0.25 V at rest, the firmware's `rail_drop_mv` for the SS54.|`main.rs`|
|2S under load|7.73 V at rest, 7.40 V at the grid's 100% rung: 0.21 Ohm of pack, diode and wiring.|nb10 sec 7|
|Rest noise|3.8 mV.|nb10 sec 3|

### Temperature

TH1 (10K / 3950 to `GND`) under Rn1 10K reaches `A0` with JP2 on `NTC`-`IN`. An external 10K / 3950 on J7 reads the same way under a 10K pull-up to `+3V3`, with JP2 on `EX`-`NTC`. Firmware publishes `ntc_raw` counts only, and the host converts:

R = 10K x raw / (4095 - raw), T = 1 / (1 / 298.15 K + ln(R / 10K) / 3950) - 273.15 °C

as `ntc_c` in [`oscnb/thermal.py`](../../../notebooks/oscnb/thermal.py) does. An external NTC taped to the MG90's can logged it every minute through the overnight rest series in `notebooks/telemetry/mg90-a__dev-v006-2A__2s__rest` (`ambient.csv.gz`).

### Position

The pot is ratiometric on `VDD`, so reference drift cancels, and the 24 MHz ADC clock above is what keeps the pot's codes (96% of those crossed, against 63% at 48 MHz). Calibration, the position table and identification are per servo and stored on it. On board #1 the MG90's table moves slowly with running ([notebook 12](../../../notebooks/12-pot-table-free-vs-governed.ipynb)), so recalibrate from time to time.

### Still open

- Board power draw (idle, torque off) is unmeasured.
- `VDD` on board #1 is not metered. Absolute volts and amps use the declared 3.300 V; board D measured 3.28 V.
- No meter lap on the terminals or the rail, and no grid dataset with both taps live: the terminal chain against a meter, the B-side low path and drive-direction symmetry are ungraded.
- The settle gain's truth checks: a normal-mode grid ladder with the table on, whether the slow tail scales with the step (grid bursts at about 13 and 40 Ohm), and a stalled motor ladder against a series meter. The table gets tuned if they disagree.
- The MG90 terminal capacitance behind the edge spike is inferred from the current, not metered.
- Every floor figure is on 2S; the LinkE 5 V supply is not characterised.
- The averaging-tap option on Cv1 / Cv2.
- The encoder inputs (J6 / J11), Qwiic and `POS2`.

## Reference designators

Passives are numbered by the net they serve, not by the sheet they are drawn on. One letter means one thing across R, C and D, so `Rv1` and `Cv1` are part of the same divider. U, J, JP, TP, NT, TH, H and LOGO keep plain numbers.

|Letter|Family|Examples|
|---|---|---|
|`f`|OPA feedback|Rf1, Rf2|
|`g`|OPA gain|Rg1, Rg2|
|`c`|OPA compensation|Cc1 - Cc4|
|`i`|OPA input|Ci1|
|`o`|OPA output|Co1|
|`d`|VREF divider|Rd1 - Rd3, Cd1|
|`k`|Kelvin taps|Rk1, Rk2, Ck1|
|`s`|Shunt|Rs1|
|`v`|Terminal and supply dividers|Rv1 - Rv6, Cv1 - Cv3|
|`b`|VB bias|Rb1, Rb2, Cb1, Cb2|
|`n`|NTC|Rn1|
|`p`|Power input and LDO|Cp1 - Cp3, Dp1, Dp2|
|`l`|Lamps (LEDs and their resistors)|Dl1 - Dl4, Rl1 - Rl4|
|`u`|MCU supply and debug|Cu1, Cu2, Ru1|
|`q`|Qwiic I2C|Rq1 - Rq4|
|`h`|H-bridge|Ch1 - Ch5, Rh1, Rh2|
|`a`|Angle sensor (pot)|Ra1, Ca1|
|`x`|One-wire bus|Rx1, Rx2, Dx1|

## LEDs

All four are deliberately dim, in the 0.1-0.3 mA class.

|LED|Ref|Color|Meaning|
|---|---|---|---|
|`VSYS`|Dl1|yellow|System rail present.|
|`3V3`|Dl2|green|Logic rail up.|
|`DAT`|Dl3|blue|Servo bus activity (active low). Passive lamp on the `DATA` line, no firmware involved. At the schematic's 4K7 (Rl3) it is faint on board #1; 1K is the brighter swap.|
|`STA`|Dl4|red|Servo health (`PC7`, active low), never traffic. In precedence order: lit for a 150 ms lamp test at boot, solid while a fault is latched (until the torque ack clears it), a 1 Hz blink while `data_flags` names a reason closed loop is refused (not calibrated, plant unset, stamp mismatch), dark when healthy.|

## Test points & probing

Nine 1.0 mm probe pads, labeled on silk. Seven sit in two rows between the position header and the sense network; `OPA` sits beside the MCU on the op-amp output, and `VS` beside the LinkE header. They take a scope tip or a pogo pin; nothing clips on, so for hands-free capture solder a wire loop to the pad.

|Silk|Ref|Net|What it is|
|---|---|---|---|
|`GND`|TP1|`GND`|Ground for the two-row group.|
|`OPA`|TP2|`OPA_OUT`|Op-amp output, ADC `A7`. Inline on the trace into `PD4`.|
|`IN1`|TP3|`DRV_IN1`|H-bridge PWM input 1 (`PC6`, TIM1 CH3).|
|`IN2`|TP4|`DRV_IN2`|H-bridge PWM input 2 (`PC5`, TIM1 CH2).|
|`VA`|TP5|`VSNA`|`MOT_A` divider tap, ADC `A5`. Inline on the trace into `PD5`.|
|`VB`|TP6|`VSNB`|`MOT_B` divider tap, ADC `A6`. Inline on the trace into `PD6`. Not the bias node `VB`, which is probed at Cb2.|
|`VS`|TP7|`VSNS`|`VSYS` divider tap, ADC `A2`.|
|`VP1`|TP8|`VPOS1`|Position channel 1 after its RC filter, ADC `A1`.|
|`VP2`|TP9|`VPOS2_NTC`|Position channel 2 or the NTC divider after its RC filter, ADC `A0`. Follows JP2.|

`OPA`, `VA` and `VB` are in the signal path, so the pad adds no stub to those nets. The rest are short spurs off filtered or driven nodes. `VREF` has no pad: probe across `Rd3`. The kelvin pair `ISNS+` / `ISNS-` has no pad on purpose. The 4x M2 mounting holes (2.2 mm) are tied to `GND` for an alligator clip.

## Power and grounding

Battery (`VBAT`) and LinkE 5 V (`VPROG`) OR into `VSYS` through Dp1 / Dp2. The SS54s drop about 0.25 V at rest (the firmware's `rail_drop_mv`, which a host adds back to `VSYS` for the pack voltage), and they block regenerated current from flowing back into either supply. `VSYS` is the raw motor rail and also feeds the LDO. `+3V3` is logic and, through Rh2, the DRV8212P VCC (`+3V3_DRV`). Rh2 ships as 0R; it is the swap point for a ferrite (600 Ohm at 100 MHz) if driver noise ever shows on the MCU rail, which is also the ADC reference.

The bridge decoupling (Ch1 100nF on `+3V3_DRV`, Ch2 100nF plus Ch3 / Ch4 10uF plus Ch5 100uF on `VSYS`) returns to `GND`, not `PGND`. That is deliberate. At PWM timescales the motor current loops cap to bridge to motor to `PGND` and back to the cap. If those caps landed on the `PGND` side, the loop would close without crossing the shunt and the ADC would only see average draw instead of the real chopped current.

`PGND` is a tiny top-layer island: the driver's GND pins and thermal pad, Rh1, NT1, and the `PGND` side of the shunt. Nothing else.

## Programming

Use a **WCH-LinkE** on J2. The link talks the CH32V006's 1-wire protocol on `SWDIO`.

### First boot

The MCU's `nRST` and the op-amp `+` input share pin `PD7`. Fresh chips come out of the factory with `RST_MODE=10`, so the pin is reset, and the sense network parks it near GND, which would hold the MCU in reset if it were connected. JP1 breaks the link until the option byte is flipped:

1. Make sure JP1 is open (no solder bridging the pads).
2. Flash the board, then program the USER option bytes over the WCH-LinkE to set `RST_MODE=11` so `PD7` becomes a GPIO.
3. Close JP1 with a small solder blob.

Do not close JP1 early. On an unprovisioned chip the op-amp network holds the pin near GND and the chip sits in reset. Recovery is reopening the jumper.

After this, the board runs as designed and current sense is live.

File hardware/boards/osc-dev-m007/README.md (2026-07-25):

# OSC Dev M007 - Rev A

> ⚠️ **Designed, not fabricated yet.**
> No physical copy of this board has been built or tested. Everything below is design intent, written before the first article. If you fab one before that happens, you are the test pilot.

The development board for OpenServoCore's M007 servo brain. One chip - the CH32M007, 3 × 3 mm - contains the microcontroller, the motor gate driver, the current-sense amplifier, and the 5 V regulator. Add six small MOSFETs and it drives a brushed servo motor (SG90/MG90 class) or a small 3-phase BLDC, measures motor current, reads a position sensor, and talks on a single-wire bus.

This is the bench version: everything on a labelled connector or test point, screw terminals for the motor, room to probe. The matching production board ([osc-sg90-m007](../osc-sg90-m007/)) squeezes the same circuit into an SG90 case; this one spreads it out on 50 × 50 mm so it is easy to work on.

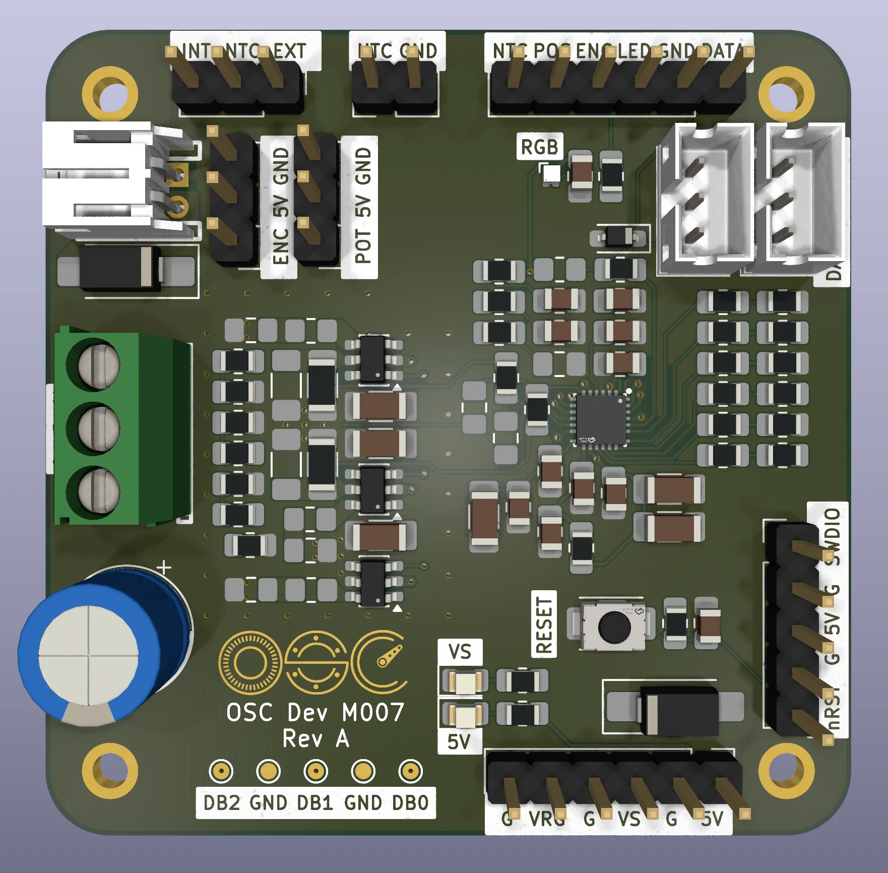
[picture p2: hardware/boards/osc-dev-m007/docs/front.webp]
Front

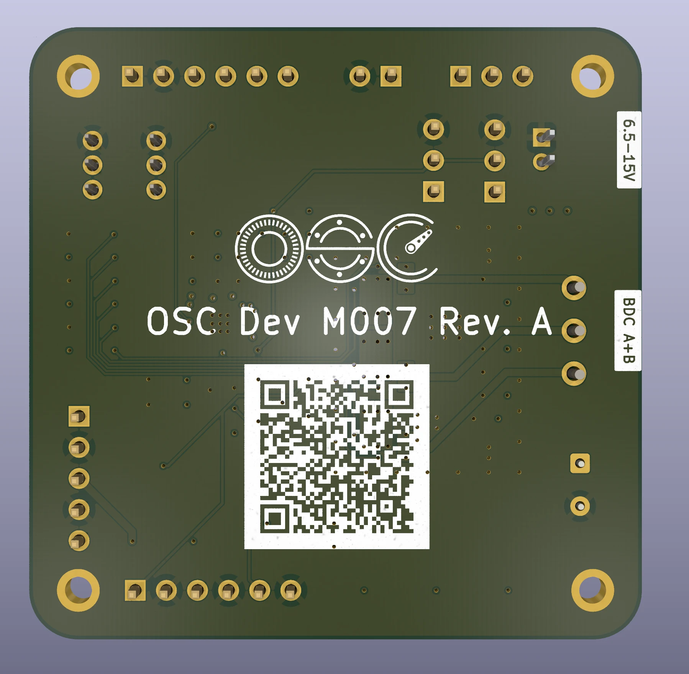
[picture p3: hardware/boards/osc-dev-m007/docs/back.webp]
Back


## What you need

- **Power between 6.5 and 15 V** - a 2S or 3S LiPo, or a bench supply.
- A **WCH-LinkE** debug probe (about $4) to flash firmware and read logs.
- Something to move: a gutted hobby servo (motor + potentiometer), a bare DC motor, or a small gimbal-class BLDC.

## Board tour

Every connector is labelled on the silkscreen:

| Silk label | What it is |
| --- | --- |
| `+` `-` (JST, top left) | Battery input, 6.5-15 V, reverse-polarity protected |
| `A B C` (screw terminal) | Motor. Brushed motor uses A and B; BLDC uses all three |
| `DATA VS GND` (two JSTs) | The servo bus. Two jacks so boards daisy-chain; `VS` is the raw supply rail |
| `POT 5V GND` | Servo potentiometer (wiper to `POT`) |
| `ENC 5V GND` | Encoder input - analog voltage, or PWM like an AS5600 |
| `INT NTC EXT` | Temperature source jumper: onboard sensor (`INT`) or your own thermistor on the `NTC GND` header (`EXT`) |
| `SWDIO G 5V G RST` | Debug/flash header for the WCH-LinkE |
| `G VRG G VS G 5V` | Power-rail probe header, every second pin is ground |
| `NTC POS ENC LED GND DATA` | Signal breakout for a scope or logic analyzer |
| `DB0` `DB1` `DB2` + `GND` | Firmware timing probe pads |
| `RGB` | WS2812 status LED |
| `VS` / `5V` LEDs | Power indicators: motor rail / logic rail |
| `RESET` | Reset button |

## Powering it

Three ways in, and they can be combined freely:

1. **Battery jack** - 2S or 3S LiPo. This input has a protection diode, so a reversed pack does nothing instead of damage. The diode costs ~0.4 V, so a nearly-empty 2S may dip under the motor's 6.5 V floor a little early.
2. **Bus jack `VS` pin** - wired straight to the rail, no diode. This is how a servo receives power in a robot, and the better path for high-current bench work.
3. **The LinkE's 5 V** through the debug header - powers the logic only.

The one rule to internalize: **the motor only runs above about 6.5 V.** The gate driver refuses to switch below that - a built-in safety property, not a fault. In practice:

- On 5 V from the LinkE, everything except the motor works: the MCU boots, firmware flashes, the bus talks, sensors read. **A dark motor on USB-level power is normal, not a broken board.**
- A 1S battery (4.2 V) can never drive the motor. 2S minimum.

The FETs are sized for roughly 2 A continuous and 3 A bursts - enough for every SG90/MG90/MG996R-class servo. A hardware comparator cuts the bridge at about 2.5-2.75 A on its own, even if firmware hangs.

## Hooking up a servo

The core experiment - turning a $2 servo into a smart one:

1. Open the servo and unsolder its factory PCB.
2. Motor wires → screw terminals `A` and `B`.
3. Potentiometer → the `POT 5V GND` header, wiper to `POT`.
4. Power and bus → one of the JST bus jacks.

The board measures motor current through two small shunt resistors and the chip's built-in amplifier - about 1 mA per ADC count - so firmware can feel load and stall without any extra parts.

For temperature, the onboard sensor (`INT` jumper) tracks the board. For motor experiments, tape a 10 k NTC thermistor to the motor can, wire it to `NTC GND`, and move the jumper to `EXT`.

## Talking to it

The bus is one shared 5 V wire plus power and ground. Every servo hangs on the same three wires, each with its own address, at up to 3 Mbaud. The wire format is the [osc-native protocol](../../../docs/osc-native-protocol.md) - OSC's own break-framed protocol, in the spirit of Dynamixel but designed for very cheap MCUs.

On the host side, a second WCH-LinkE flashed with the [adapter firmware](../../../firmware/boards/osc-adapter-wchlinke/) becomes the USB-to-bus interface.

## Flashing firmware

Connect a WCH-LinkE to the debug header - `SWDIO` and `G` at minimum, plus `5V` if the probe should power the board - and flash with [wlink](https://github.com/ch32-rs/wlink). Firmware v2 for the M007 is in bring-up; the transport and protocol layers are proven on the V006 family and the M007 uses the same USART hardware. Check the repo root [README](../../../README.md) for current status.

## Specs

| | |
| --- | --- |
| Brain | CH32M007E8U7 - 48 MHz RISC-V MCU + gate driver + current-sense amp + 5 V regulator, one QFN-26 |
| Supply | 6.5-15 V (2S/3S LiPo) |
| Motor | Brushed H-bridge or 3-phase BLDC, ~2 A continuous / 3 A burst |
| Current sense | Two 75 mΩ shunts, on-die amplifier, ~1 mA resolution |
| Overcurrent | Hardware comparator trip at ~2.5-2.75 A |
| Feedback | Potentiometer, analog/PWM encoder, NTC (onboard or external) |
| Bus | Single-wire half-duplex, 5 V logic, 0.5-3 Mbaud |
| Size | 50 × 50 mm, 6-layer, M2 mounting holes |

## Building one

The board is designed around JLCPCB's 6-layer promo: 50 × 50 mm, all vias 0.3 mm, epoxy-filled vias (select "Epoxy Filled & Capped"), which prices at a few dollars for five boards and forces ENIG (gold) finish - which also makes hand assembly nicer.

- Every part has its LCSC number in the schematic; the passives are 0805, chosen for easy hand soldering.
- One genuinely hard joint: the QFN-26 with its center pad. That pad ties into the board's internal copper planes, which soak up heat - hot air from the top alone usually can't get the joint to reflow. Heat the board from below with a hotplate (paste stencil, place the chip, reflow the whole side), using hot air on top only as a finisher. Everything else is beginner-friendly.
- Parts marked DNP ("do not populate") in the schematic are options and tuning pads. Leave them empty - that IS the standard build. Some of them change how the board behaves (shunt value, sense filtering), so only mount one if you know exactly why you want it.

## More reading

- [osc-native protocol](../../../docs/osc-native-protocol.md) - the wire protocol
- [servo transport](../../../docs/osc-servo-transport.md) - how the servo side keeps up at 3 Mbaud
- [design history](../../../docs/design-history.md) - how the project got here

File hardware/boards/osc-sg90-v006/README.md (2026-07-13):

# OSC SG90 CH32

> ⚠️ **Designed, not spun. Pre-fabrication, pre-bringup.**
> This board has never been fabbed. Numbers and behaviour described below are **design intent**, not measured. The schematic and layout exist; firmware v2 now runs on the dev board (the bus transport is silicon-proven) but has never run on *this* board. Don't fab this without doing your own review first, and expect changes when bringup finally happens.

OpenServoCore swap board for SG90-class hobby servos. Compact, double-sided, designed to physically replace the factory PCB inside an SG90 case. CH32V006-based, single-wire TTL servo bus (osc-native protocol), drop-in mechanical fit.

## Overview

- **MCU** — CH32V006F8U6 (RISC-V, 48 MHz, 62 KB flash, 8 KB RAM).
- **Motor driver** — TI DRV8837 H-bridge (1.8 A peak, IN1/IN2 PWM).
- **LDO** — TPAP2210K-3.3, 3.3 V logic rail.
- **UART buffer** — SN74LVC1G07 open-drain for the half-duplex TTL bus.
- **Current shunt** — 25 mΩ, 1 % on the low side.
- **Power input** — 3.3-8.4 V (1S-2S LiPo) via the servo cable.
- **Debug** — 4-pad SWD interface for WCH-LinkE.
- **Position feedback** — existing servo potentiometer wiper.
- **Form factor** — 10 × 12.5 mm, double-sided assembly.

## Connectors

### Servo cable — J1 (1×3, through-hole pads)

Standard hobby-servo 3-wire pinout, but the signal pin carries half-duplex UART instead of PWM:

| Pin | Net | Notes |
| --- | --- | --- |
| 1 | `VIN`  | 3.3-8.4 V (1S-2S LiPo). |
| 2 | `DATA` | Half-duplex UART, baud TBD by firmware. |
| 3 | `GND`  | |

### Motor — J2 (2 wire pads)

Solder directly to the SG90 motor leads.

| Pad | Net |
| --- | --- |
| `OUTA` | Motor terminal A |
| `OUTB` | Motor terminal B |

### Potentiometer — J3 (3 pads)

Connects to the existing servo potentiometer.

| Pad | Net |
| --- | --- |
| `+3V3` | Pot top rail |
| `VPOS` | Wiper |
| `GND`  | Pot ground |

### Debug — J4 (4 pads, 1.27 mm pitch)

Single-wire SWD for WCH-LinkE. Programmed via `wlink` / `probe-rs`. Firmware build instructions land when firmware v2 starts; until then there's nothing to flash.

| Pad | Net |
| --- | --- |
| 1 | `+3V3`  |
| 2 | `GND` |
| 3 | `SWDIO` |
| 4 | `NC` |

## Design intent

These are the targets the board was laid out around. None are measured.

- **Power architecture** — VIN routes to the DRV8837 directly; 3.3 V logic rail off the TPAP2210K LDO. Bulk capacitance is 2× 10 µF on VIN. PGND/GND joined at a single net tie.
- **Position sensing** — 12-bit ADC on `VPOS` with an RC filter (10 kΩ + 100 nF, fc ≈ 160 Hz) to suppress wiper noise. Sub-degree resolution is the design goal; actual precision waits on bringup and firmware oversampling.
- **Voltage sensing** — 20 kΩ / 10 kΩ dividers (ratio 0.333) on `VINS`, `VSNA`, `VSNB`. 8.4 V → 2.8 V at the ADC.
- **Current sensing** — 25 mΩ low-side shunt, sized for the DRV8837's ~1.76 A peak via `R_shunt ≈ 44 mV / I_stall`, so the hardware stall-detect path trips near the driver's max output. Raw V_shunt = 25 mV at 1 A; firmware sets ADC sampling, gain path, and software overcurrent threshold.
- **Communication** — single-wire half-duplex TTL servo bus (Dynamixel-TTL electrical layer; the wire protocol is [osc-native](../../../docs/osc-native-protocol.md)). The SN74LVC1G07 open-drain buffer enables bidirectional comms over the single `DATA` line. Bus rates: 0.5-3 Mbaud, default 1 M.
- **Protection** — PESD5V0L1UL TVS on `DATA`.

## Assembly

Double-sided assembly, no vias-in-pads. Suitable for hot-plate / hot-air / IR reflow, or JLCPCB SMT. The board is 8-layer for routing density at this size.

## Mechanical fit

Designed to drop into a standard SG90 servo case:

- Motor leads solder to `OUTA` / `OUTB`.
- Pot wiper connects to `J3`.
- Servo cable connects to `J1`.
- Debug pads remain accessible through the case opening for bringup / reflashing.

Pad spacing for motor leads and debug pitch are still **to be confirmed against a physical case** when first boards arrive.

## License

Hardware files (schematic, layout, board files in this directory) are licensed under [CERN-OHL-P v2.0](../../../LICENSE-HARDWARE). See the [top-level README](../../../README.md#license) for the full licensing picture.

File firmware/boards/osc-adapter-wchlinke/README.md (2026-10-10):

# osc-adapter-wchlinke

The osc bus adapter runs on a stock WCH-LinkE (CH32V305FBP6). One physical
dongle plays two roles, and you flip between them entirely over USB - no
second probe, no button, no soldering:

- **Stock WCH-LinkE probe** (`1a86:8010` RV mode): flashes and debugs targets
  with `wlink`, provides SDI print, powers the DUT rails.
- **osc adapter** (`1209:0001`): the osc-host instrument this crate builds -
  bus scheduling, rail control, bench tooling via `tools/osc`.

## How the flip works

The CH32V305's factory ISP is unreachable on this package, but WCH's LinkE
firmware ships as an 8 KB IAP loader (flash `0x0000`, USB `4348:55e0`) plus
an APP image at `0x2000`. Both the stock firmware and this adapter are APP
images under that same preserved loader:

- The loader jumps to the APP only when the APP-validity words sit at image
  offsets `0x50`/`0x54` (`0x12345678` / `0x39373533`) AND its arm flag
  (byte 5 of the `@WCH` signature at `0x08037F08`) reads `0x5A`. This crate
  plants the validity words through vector-table entries 20/21 (`src/main.rs`;
  CI gates the placement via `.github/check-iap-header.sh`).
- Flashing through the loader re-arms the flag automatically, so a freshly
  flashed APP boots on the next reset without any manual step.

## Tooling (one-time setup)

- **wlink-iap** - cjacker's IAP flasher: <https://github.com/cjacker/wlink-iap>
  (`make && sudo make install`, or keep the binary on PATH).
- **Stock firmware image** - `FIRMWARE_CH32V305.bin`, extracted from WCH's
  [WCH-LinkUtility](https://www.wch.cn/downloads/WCH-LinkUtility_ZIP.html)
  install directory (the utility bundles per-probe firmware; v2.22 known
  good). Community mirrors exist but treat wch.cn as authoritative.
- **Adapter image** - build from this crate:

  ```sh
  cd firmware/boards/osc-adapter-wchlinke
  cargo build --release
  llvm-objcopy -O binary \
      target/riscv32imc-unknown-none-elf/release/osc-adapter-wchlinke \
      osc-adapter.bin
  ```

  (`llvm-objcopy` ships with the Rust `llvm-tools` component; the image is
  linked at `0x2000` under the loader - see `memory.x`.)

## Adapter -> stock LinkE

```sh
osc bootloader                        # adapter disarms the loader flag + resets
                                      # device re-enumerates as 4348:55e0
wlink-iap -f FIRMWARE_CH32V305.bin    # flash stock APP; loader re-arms itself
```

The dongle boots straight into the stock probe (`1a86:8010`). Verify with
`wlink list`. Two gotchas after a flip:

- Stock firmware boots with the **5V output OFF** (3V3 is on for SWD). If the
  DUT's motor rail rides the LinkE 5V: `wlink set-power enable5v`.
- No replug is needed; if the host USB stack sulks, replug is harmless.

## Stock LinkE -> adapter

```sh
wlink-iap -i                          # stock probe -> IAP mode (4348:55e0)
wlink-iap -f osc-adapter.bin          # flash the adapter APP
```

`wlink-iap -i` speaks the stock link-mode protocol to enter IAP; from the
adapter side that door is `osc bootloader` (the adapter does not implement
the stock protocol). Verify with `osc info` (enumerates as `1209:0001`).

## Bus wiring

DATA is the header TX pin (PB10), single wire, plus GND. The adapter only
ever sinks the line (open-drain), so DATA needs a pull-up at the adapter
end: 680 ohm to the header 3V3 on the bench pigtail. Keep the 3V3 rail on
while a separately powered servo is on the bus: with the rail off the
pull-up becomes a pull-down, and the servo reads a held low as a rescue.

## Diagnostics

`osc info` also prints what the adapter recorded about its last reset: the
RCC reset cause (PIN/POR/SFT/IWDG), the main-loop phase the reset caught,
and the last trapped exception (mcause/mepc/mtval, with a running count).
The record lives in a reserved RAM word block that survives resets; a
synchronous exception records itself and resets, and an independent
watchdog (2 s nominal) resets a hung loop, so either way the dongle
re-enumerates on its own instead of dropping off the bus.

It also prints the adapter's uptime and its reset count since the last
power-on (kept in the same block, zeroed by a POR). After a USB drop, an
uptime shorter than the time since the drop means the adapter restarted;
one longer means it kept running and the host lost the link.

## Recovery

The loader is never erased by either direction, so a broken or interrupted
APP flash leaves the dongle in (or bootable into) IAP mode - reflash with
`wlink-iap -f`. The loader cold-boots into IAP whenever the arm flag is
disarmed or the APP validity words are missing. Only a full-flash corruption
(e.g. SWD writes below `0x2000`) needs a second probe clipped to the SWD
header to restore a full image.

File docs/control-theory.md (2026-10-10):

# Control Theory

This document is the control theory behind the OSC servo firmware, written ahead of the implementation so the code has something to be checked against. It is self contained. No control background is required beyond a rough idea of what a PID loop is.

The short version: a classic three-loop cascade, a current loop inside a velocity loop inside a position loop, plus an estimator layer that turns whatever sensors are present into estimates of position, velocity, torque, and temperature. Better sensors upgrade the estimates. The loops themselves never change.

Notation first. A star means a target ($\theta^{\ast}$), a hat means an estimate ($\hat\theta$). Subscript $m$ is the motor shaft, subscript $\text{out}$ is the output shaft after the gearbox.

## Where This Design Comes From

Before diving in, I want to be honest about where this design comes from. It is built on the inspirational work of Adam Bäckström's [ServoProject](https://github.com/adamb314/ServoProject), design sessions with Claude (Anthropic's Fable 5 model), and my own limited understanding of control theory. I'm not a professional embedded developer or a control theory guy. I did CE/EE in school and took some basic control theory courses, and that was enough to drive parts of this design, but only to a limited degree.

So if you see any issues or errors in the design, or would like to contribute ideas, feel free to leave a message on the [discussion board](https://github.com/OpenServoCore/open-servo-core/discussions). I'd love to hear your thoughts.

## The Plant

The thing being controlled is a brushed DC motor driving a gearbox. Three equations describe pretty much all of it:

$$v = R(T)\cdot i + L\cdot \frac{di}{dt} + K_e\cdot \omega_m \qquad (1)$$

$$K_t\cdot i = J\cdot \frac{d\omega_m}{dt} + \tau_f(\omega_m) + \tau_\text{load} \qquad (2)$$

$$\theta_\text{out} \approx \theta_m / N \qquad (3)$$

Equation (1) is the motor's electrical equation, the voltage across its terminals. The voltage splits three ways. Some is burned in the winding resistance $R$, some goes into the winding inductance $L$ while current is changing, and the rest fights the back-EMF $K_e\cdot \omega_m$. Back-EMF is the voltage the motor generates just by spinning. It is proportional to speed, and $K_e$ is the proportionality constant.

Equation (2) is the mechanical equation, Newton's second law for the rotor. Current makes torque, $\tau = K_t\cdot i$, and the torque splits three ways just like the voltage. Some goes into accelerating the rotor inertia $J$, some is eaten by friction, and the rest pushes whatever load is on the shaft.

Equation (3) is the gearbox. It divides the motor angle by the gear ratio $N$. The $\approx$ is hiding backlash. Backlash is the slop between gear teeth, so the output can wiggle a little without the motor moving, and the two angles disagree by up to the slop width depending on which direction was driven last.

A neat fact: $K_e$ and $K_t$ are the same number in SI units. Measure one and you have the other.

Two details in there do a lot of work later. First, $R$ depends on temperature. Copper gains about 0.393% resistance per °C, so a motor that heats up 40 °C is a motor whose resistance grew by about 16%. Second, friction in a cheap gearmotor is big, mostly Coulomb friction (a constant drag that flips sign with direction) plus a viscous term:

$$\tau_f(\omega) = \tau_c\cdot \text{sign}(\omega) + b\cdot \omega$$

## Why a Cascade

You could control position with one big PID straight from position error to PWM duty. That is basically what a stock hobby servo does, and it works, sort of. The problem is that one loop has to deal with three very different kinds of physics at once. Electrical dynamics settle in microseconds, velocity in milliseconds, position in tens of milliseconds. One set of gains cannot be tight on all three at the same time, so it ends up loose on all of them.

The cascade splits the job into nested loops, fastest on the inside:

cascade

- The **current loop** runs at the PWM rate. Current is torque, so this is really the torque loop.
- The **velocity loop** runs about ten times slower and commands current.
- The **position loop** runs at a similar or slower rate and commands velocity.

On the servo the slower rate is a 2 kHz period of ten PWM ticks, and its work is spread over those ticks in the order the data flows: the host's commands and the edges first, then the observer on that tick's sample, the trajectory and the position loop, the limits, the velocity loop, the rail estimate and the detectors, and the publishes last. The current command lands three ticks (150 µs) after the sample it was computed from.

The tick index is the sample clock, and every executed tick is one period. The kernel interrupt sits above the transport, so bus traffic costs it no tick (protocol sec 5.9), and everything advances one period per tick: the phase sequence, the boxcars and filters, the trajectory, the observer's prediction, the stall and tracking-error timers that the host writes in milliseconds, and the SLOW cadence. A tick is lost only to a kernel body that overruns past two periods, a flash SAVE (torque off) or a debug halt; `tick_lost_count` counts it, and the kernel does not stretch its next step to cover it.

Each loop only has to handle one kind of physics, and each loop makes the plant look simpler to the loop outside it. By the time the position loop is involved, "apply a torque" is just a number it writes, and all the electrical mess is somebody else's problem.

The cascade also gives you limits for free. Clamp the command between two loops and you have a real physical limit. Clamp the current command and you have a torque limit. Clamp the velocity command and you have a speed limit. No special cases inside the loops.

One more rule, but it needs some background before I state it.

A P controller alone cannot hold against a constant load. Its output is proportional to error, so to keep putting out torque it must keep a standing error. Picture a servo horn holding a weight: with pure P the arm sags below the target forever, because sitting exactly on target would mean zero error and therefore zero torque. The fix is the I in PI. An integrator accumulates error over time and keeps nudging the output until the error is exactly zero, then holds the accumulated value as a standing command. It is the loop's memory.

Memory has a failure mode. When the output hits a limit, the error persists, and the integrator keeps charging up a correction it cannot deliver. When the limit releases, all that stored correction dumps out and the servo overshoots while the integrator drains back down. This is called windup, and the standard cure is back-calculation anti-windup: whenever the output clips, the clipped amount is fed back to discharge the integrator, so it never charges past what the output can actually deliver.

The second problem shows up when two nested loops both have memory. Suppose the position loop and the velocity loop each carried an integrator, and the servo sits slightly off target. Both integrators see the same standing error, one directly and one through the cascade, and both charge up to remove it. The same correction gets applied twice, the servo overshoots, both integrators start draining, it undershoots, and the result is a slow hunt around the target that no amount of gain tuning fixes cleanly.

Thus the rule: each frequency band gets at most one integrator, and every integrator gets anti-windup. In this design the current PI and the velocity PI carry the integral action, and the position loop stays pure P.

## The Trajectory Generator

Targets don't go straight into the position loop. A trajectory generator sits in front and turns a step in `goal_position` into a smooth motion profile, capped by a velocity and acceleration limit. It emits three signals at once: the position reference $\theta^{\ast}$, the velocity along the profile $\omega^{\ast}$, and the acceleration along the profile $\alpha^{\ast}$.

The last two are feedforward. Feedforward means telling the loops what is about to be needed instead of waiting for them to notice the error. If the profile says "we should be moving at 2 rad/s right now", the velocity loop gets that directly and only has to correct the small difference. This is what lets the feedback gains stay modest. Low gains ride through sensor noise, and the feedforward does the actual work of following the profile.

The target can also enter further in. Velocity mode feeds $\omega^{\ast}$ straight to the velocity loop, and torque mode feeds a current target straight to the limiter.

Before any shaping happens, the goal itself is clamped against the control table's position limits. Not every servo can swing a full turn, and a robot may add tighter mechanical limits of its own on top. Clamping at the entry works nicely with the profile: since the profile respects the acceleration limit, a goal clamped at the wall decelerates into the wall instead of slamming the reference against it. The clamp here handles the normal case only. The safety net for overshoot and external forces is the endstop term in the limits block below.

## The Position Loop

position loop

Pure proportional. Position error times $K_p$ gives a velocity command, add the $\omega^{\ast}$ feedforward, clamp to `velocity_limit`, done. No integrator here (see the rule above). Steady-state accuracy comes from the velocity loop's integrator and the feedforward. Besides, a position integrator on top of Coulomb friction is a classic recipe for limit cycling, where the servo slowly hunts back and forth around the target forever.

Once the profile has landed and the error is inside `pos_deadband_counts`, the loop parks instead of dithering against friction: the bridge shorts the winding (brake), the velocity loop is frozen with its integrator emptied, and it starts again from zero when the error leaves the band or a new goal starts a profile. The park is decided on position alone, never on the velocity estimate, which at rest is pot noise. The short is what lets a fast arrival end in the band. A shaft that trails the profile into its deceleration keeps running on the velocity limit, because $K_p$ times the deadband already asks for more than that at the band edge (157/s times 12 counts is 1884 counts/s on the MG90), so it can enter the band at speed. Friction alone stops it within the 24-count band only below about 1250 counts/s. Faster, it leaves the far edge, the loop wakes with a velocity error far beyond what the current limit allows, kicks the shaft back at the limit, and it crosses the band at speed again: a limit cycle. The shorted winding adds a braking current $K_e\,\omega/R$, so the band stops arrivals up to about 2100 counts/s. At rest that current is zero and the rail supplies nothing. A hand turning the horn inside the band feels it as viscous drag, $K_e^2/R$ at the output, about 0.56 mN·m per °/s on the MG90, and past the band edge the loop pushes back.

The deadband is counted in raw counts of the position sensor, not in the linearized counts the error is in. What it has to absorb, sensor noise and quantisation, lives in raw counts, and the position table's local gain $g$ (linearized counts per raw count, 0.50 to 2.06 across the MG90's pot) stretches it on the way to the error. So the band is `pos_deadband_counts` times $g$ at the present position: 12 raw counts are about 19.5 linearized counts where the MG90 rests at $g = 1.62$. A band of 12 linearized counts there is only 7.4 raw counts, narrow enough for pot noise to wake a parked loop. The figures above are at $g = 1$, which is also the band with no table live. The scale is clamped to 0.5 to 4: real pots sit inside that, and a corrupt table can neither shrink the band under half the deadband in shaft angle, where the gear lash lives, nor stretch it past four deadbands.

## The Velocity Loop

velocity loop

A PI controller plus feedforward of everything the mechanical model already knows:

- $J\cdot \alpha^{\ast}$, the torque needed to accelerate along the profile.
- $\tau_f(\omega^{\ast})$, the friction model evaluated at the profile velocity.
- $\tau_\text{cog}(\hat\theta_m)$, a small position-dependent torque ripple map.

This block is the mechanical half of the motor model run backwards, from the motion I want to the torque it takes. (The electrical half of the model shows up later, as the current loop's decoupling terms.) Its inputs come from three different places: $\alpha^{\ast}$ from the trajectory generator, $\omega_\text{ref}$ from the position loop's output, and $\hat\theta_m$ from the estimator layer. The $\hat\omega$ it subtracts is the selected velocity source, which is the back-EMF estimate whenever that estimate is valid and the pot observer's velocity otherwise. The estimator section below has the switch.

All three are divided by $K_t$ to become a current command. The friction term matters the most. On a gearmotor the Coulomb term dominates, and feeding it forward is the difference between tight low-speed tracking and tracking that feels like molasses. The PI then only cleans up what the model missed.

The integrator uses back-calculation anti-windup. When the limiter downstream clips the command, the difference is fed back to shrink the integrator, so it never charges up against a limit it cannot push through.

## Limits

limits

The current clamp is the one choke point every command passes through, so it is where all protection lives. The limit `i_lim` is the minimum of four terms, and each one is doing a different job:

- **`torque_limit`** protects the gear train. This is the tooth saver on a plastic-geared servo, and the yield behavior comes for free. Push the output harder than the limit and the servo cannot fight back harder than $K_t \cdot i_\text{lim}$, so it gives way while the position error grows. Let go and the error is still standing there, so it pulls right back. No special mode needed, that is just what a saturated cascade does. A stock servo strips teeth exactly because it has no current loop, a stall there means maximum current for as long as the fight lasts.
- **`derate(T̂wind)`** protects the copper. It is a foldback curve. Below a threshold temperature it does nothing, above it the ceiling ramps down, reaching zero at the absolute max. The nice part is that this self-regulates. Less allowed current means less heating, so the servo settles at a thermal equilibrium of "weaker but still holding" instead of banging on and off. A hard cutoff plus an alert flag sits at the absolute max as a last resort, and the ramp should keep it from ever being reached.
- **stall policy** covers the losing fight. Current pinned at the limit with the pot observer's $\hat\omega \approx 0$ (equivalently, a large steady $\hat\tau_d$) means the servo is stalled against something. The pot observer is the right source here for the reason the estimator section gives: it is the one that still means something at rest. After a timeout the limit folds to a lower yield torque so it stops cooking itself, and restores when $\hat\tau_d$ relaxes. (Set `stall_response` to Fault, which is also the boot value, and the timeout latches a stall fault instead of folding.) A $\hat\tau_d$ spike counts too: a collision detected by the observer can drop the limit within one control cycle, which is what protects the teeth from shock loads rather than static ones. That spike needs a motor model to mean anything: while the model is unset, predict explains none of the motion, so $\hat\tau_d$ would just integrate plain position error, and the observer holds it at zero instead. On an unidentified servo the collision check is therefore off and the stall timer carries the protection alone.
- **`endstop(θ̂)`** enforces position limits, the other half of the goal clamp in the trajectory generator. It is directional: when $\hat\theta$ sits at or past a limit, current pushing further in gets clamped toward zero while current pulling back out stays allowed. The servo can always retreat from a wall and never gets stuck fighting itself, and the protection holds even when overshoot or an external force carried it past the limit with a perfectly legal reference.

Whatever clips here back-propagates to the velocity integrator as described above.

### Open Loop Under the Same Band

Everything above clamps a current command, and open-loop mode has none. The host writes a duty and the bridge applies it, which is exactly what calibration and identification want, and exactly what a stalled rotor turns into its full stall current, $d\cdot V_\text{bus}/R$. For an MG90 winding of 4.9 ohm on a 7.9 V pack, 64% duty stalls at $0.64\cdot 7.9/4.9 = 1.03$ A, over three times the 0.30 A of static stall at which micro-class teeth and end stops show damage (class defaults, below). So open loop gets the same band enforced a different way: a duty ceiling, driven by the shunt alone. No gains, no identified constant, no multiply, so it works from the first boot of an unconfigured servo.

The numbers in this section come from the kernel pins that drive an MG90-scale motor model: that 4.9 ohm winding, the 7.9 V rail, the development board's 60 mohm shunt chain at 1117 counts per amp, and a limit of 280 counts (0.25 A) unless stated otherwise.

Once per fast tick the limiter compares the measured current $i$ against $i_\text{lim}$, the side of the band the goal points into (so the derate, the stall fold, the endstop and the stall permit all reach open loop through it), and moves the ceiling $c$ by one of three rules:

- **Below the band**, $i \lt i_\text{lim} - i_\text{lim}/8$: the ceiling rises by 128 in Q15, 0.39% of full duty per tick, which is 7.8% per millisecond at 20 kHz.
- **Inside the band**, from $i_\text{lim} - i_\text{lim}/8$ up to $i_\text{lim}$: the ceiling holds.
- **Over the limit**: the ceiling drops by eight Q15 steps per count of overage, $c \leftarrow c - 8\cdot (i - i_\text{lim})$.

Then $c \leftarrow \min(c, d_\text{goal})$, so a goal cut applies at once, and the applied duty is $c$ with the goal's sign.

The hold band is what makes a stall quiet. Without it the ceiling rises and drops in turn around the limit forever, a limit cycle, and the band gives it somewhere to stand. The proportional drop sizes each correction to the overage, so a sudden stall comes down in steps as big as the problem rather than a fixed step at a time. It is also gentle enough not to overshoot on its own: a duty change $\Delta d$ moves the stall current by $\Delta d\cdot V_\text{bus}/R$, which on the rig is $3204/32768/1.775 = 0.055$ counts per Q15 step (a 3204-count rail over a winding of 1.775 voltage counts per current count), so a drop of 8 per count removes 0.44 of the overage it saw, under one.

Rising at a fixed rate is the first-edge protection. The shunt reports a window one tick late, so no loop, fast or slow, can catch a duty step before the current has already followed it. The answer is to never let the step exist: every rise above the window floor is a slew, and every start to a goal above the floor climbs from the floor. The ceiling restarts at the floor whenever the drive starts or stops (torque on, torque off, a fault latching), on a mode change while torque is on, and whenever the goal's sign differs from the applied duty's, which covers a reversal and a start from zero duty alike.

#### The Blind Band Under the Floor

Below the window floor of the next section the shunt reports nothing, and the limiter reads the missing sample as zero current, the same honest zero the current loop uses. A ceiling down there would rise forever on a current it cannot see, so under the floor the limiter stops trusting its ceiling and applies a stall-safe base duty instead:

$$d_\text{base} = \min\left(\frac{i_\text{lim}\cdot R}{V_\text{bus}},\ d_\text{floor}\right)$$

This is the duty whose stall current is exactly the limit. $R$ is the identified winding resistance and nothing else, so the bridge and the shunt add resistance the formula leaves out and the real stall current at $d_\text{base}$ sits a little under $i_\text{lim}$. The applied duty is $\min(d_\text{base}, d_\text{goal})$ whenever the ceiling is under the floor, which also means a goal at or under the floor passes through untouched as long as it is not above $d_\text{base}$: small seeks and breakaway ramps are not governed at all.

At a stall where even the floor draws more than the limit, the ceiling drops under the floor, the base carries the hold, and the ceiling climbing back past the floor at the slew rate is the re-probe: one measurement, and back down if the stall is still there. On the rig, with a limit of 200 counts under the floor's 239-count stall current, more than half the ticks sit in the blind band, every one of them at a duty whose stall current is 95 to 100% of the limit, and the mean current stays within 10% of it.

With no identified $R$ the base is the floor itself, so the limiter never drives itself blind. The blind band is then bounded by physics rather than by the limiter: the lowest duty the limiter applies for a goal above the floor is the floor, so stall current there is at most $d_\text{floor}\cdot V_\text{bus}/R$. With the floor at 5.3% that is 0.085 A for the 4.9 ohm MG90 winding on a 7.9 V rail, and it stays under the 300 mA class limit for any winding above $0.0529\cdot 8.4/0.3 = 1.48$ ohm on a full 2S pack. If the floor still draws more than the limit, the applied duty sits pinned at the floor and the stall timer decides.

All of this bounds the period average, the current that sets the torque, and the shunt reports something else: the current at the centre of the on time. The two agree only while the winding's $L/R$ is long against the 50 µs period. The MG90's is about 170 µs, and its centre sample sits within 1% of the average. A load with almost no inductance carries its full on current $(V_\text{bus} - e)/R$ for the length of the pulse and nothing in the brake half, so its sample reads up to $1/d$ times its average. On a bare 5.11 ohm resistor at the 5.3% floor the sample read 748 counts against a 280-count limit while a series meter read 34 mA, about the floor's share of the 669 mA on current and under a seventh of the 0.25 A limit. The limiter errs safe on such a load, and that is right: it holds the floor and pins, because driving under the floor would cut the torque under a limit the average already meets. Heat in the copper goes with the RMS current instead, up to $1/\sqrt{d}$ times the average on such a load, and guarding it is the derate's job. The base stays right too. The brake half shorts the winding, so the period average is $(d\cdot V_\text{bus} - e)/R$ whatever the inductance, and the base is built on it. Whether the floor can let the average past the limit is therefore a question of $R$, never of $L$. For a load with little inductance it takes an on current over $i_\text{lim}/d_\text{floor}$, 5.7 A at the 300 mA class limit and a 5.3% floor, far past the 2.2 A overcurrent trip. That trip still sees the re-probes at the floor, and its window holds its count through the blind ticks, so a short under the stored $R$ latches it within a few re-probes: on the rig, a load at a quarter of the stored $R$ trips in 5.9 ms. What is left is a load with little inductance and no identified $R$ under a limit below $d_\text{floor}$ times the trip, 116 mA at a 5.3% floor: there the floor can hold an average over the limit without reaching the trip. No class limit sits that low.

#### How the Stall Timer Sees It

The stall verdict wants to know that the command sat at the limit. In the closed loops that is the current reference at $i_\text{lim}$. In open loop it is the ceiling being held under the goal by the current: the limiter records a pin on any fast tick where a measured current sits at or above the band's lower edge while the ceiling is below the goal, and the medium pass takes that pin as its own. A slew never pins (the current is below the band), and a hold at the goal is not a pin either, because nothing is being refused. From there the verdict is the same as in closed loop: pinned, with the pot observer's $|\hat\omega|$ under `stall_omega_max`, for `stall_time_ms`, then the yield fold or a stall fault. The timer runs out after `stall_time_ms` plus however long the observer takes to settle on a still shaft, under 100 ms past a 500 ms timer on the MG90 gain set.

#### What It Costs an Identification Experiment

A step is clean, meaning the limiter never touches it, only if the current stays under the band's lower edge the whole time. From rest there is no back-EMF, so the current right after the step is about $d\cdot V_\text{bus}/R$ and the largest clean step is

$$d_\text{clean} = \frac{7}{8}\cdot \frac{i_\text{lim}\cdot R}{V_\text{bus}}$$

On the rig that is $0.875\cdot 280\cdot 1.775/3204 = 0.136$, a 13.6% step, barely above the floor. On a shaft running at $i_\text{run}$ the headroom is what the running current leaves, $(\frac{7}{8} i_\text{lim} - i_\text{run})\cdot R/V_\text{bus}$, which is 9.1% for a shaft drawing 80 counts. Anything bigger is governed: the duty climbs at whatever rate the current allows and reaches the goal only if the load lets it. A clean step is still a slew, 9.1% takes 24 ticks or 1.2 ms, so a fit takes the applied duty from the TEL `duty` field as its input, never an ideal step. The rule a host uses to tell a governed window from a clean one is in the protocol doc, sec 5.8.

The host tools (`osc ident` and `osc cal`, with their planning in the `ident` crate) are built around that. The numbers in this and the next three sections are the bench MG90 as the host pins model it: the 4.9 ohm winding, a limit of 280 counts (0.251 A at 1117 counts per amp), a 13.3% window floor on both sense paths, on a 7.9 V 2S pack or a 4.39 V USB rail.

Every drive is one of two kinds.

- **Stall-safe by duty.** A drive that points at a stop and can reach it, a drive with the stall permit held, and a drive that starts outside the travel guard. Once the burst has measured $R$, the host plans its duty so that a stall at it draws at most the limit, $d \le i_\text{lim}\cdot R/V_\text{bus}$: the seeks to a start position, the centring, the breakaway ramp, cal's stop approach and seat. That cap is 15.5% on 2S and 27.9% on USB, and the duty whose stall draws half the limit is 7.76% and 14.0%. Before anything in the run has measured $R$, a plan takes the $R$ the servo carries, else the lowest winding of the class, 3.0 ohm, which errs safe on every servo of it; the stop-stall routes that run only on request plan that way. The class-safe duty, 9.5% on 2S and 17.1% on USB, is also where the jam check starts.
- **Free-running.** The ladder rungs, the inertia base and steps, and cal's ripple traverse. Their duties sit well over any stall-safe duty (the ladder climbs to 64%), and they have to, because they measure a shaft running at speed. What bounds them is the firmware (the limiter holds a stall at the limit, and the stall timer folds it or latches a fault; the host takes a yield fold as a blocked shaft and ends the run), the travel guard 100 counts inside the soft limits, the host's current abort, and the runway below. A free drive runs only after the jam check has proven the shaft free (in identification, only after the burst has measured $R$ as well), and never with the permit.

The current abort sits a quarter over the limit, judged on the 0.8 ms ident window mean while a duty is applied. A climb the limiter governs holds its windows at 0.85 to 1.0 of the limit with peaks to 1.1, so an abort at the limit itself would trip on the hold's own noise. At a quarter over, only a limiter that is not holding, or a shaft that hits something at speed, reaches it. A host may lower the threshold, never raise it past that.

Governed is not a fault, it is a window the fit cannot use. Every fit reads the applied duty of each window (`duty_mean_q15`, or the TEL `duty` field) against the goal. A window still inside the slew the firmware allows is trimmed. A window the limiter held under the goal after that is governed and never fitted. A ladder rung, an inertia step or a stall dwell with no clean window at all is declined in plain words ("the current limit governed this window"), never fitted thin. A ladder rung that climbs on the limit is the normal case: its governed climb is trimmed and the settled windows fit.

A TEL burst the servo dropped rows from (`tel_drop_count`, protocol sec 5.9) is missing them, so a rate fitted over it reads fast: it is not evidence, and the run ends on it the way `osc capture` refuses such a recording.

#### The Jam Check and the Blocked Shaft

Every run starts with the cheapest proof that the shaft moves and the pot reads it. The host drives into a band 300 counts either side of mid travel, then 100 counts out and back again. It starts at the class-safe duty, and each time a whole window of polls (8 polls of 20 ms) passes with the shaft still, it raises the duty by 2.5% of full scale, up to 2 V applied: 25.3% on 2S, 45.6% on USB. The first 100 counts of travel freeze the duty. That duty is the run's estimate of what moves this shaft. Once $R$ is known the seeks drive at it plus 2%, never over the stall-safe cap, and after the breakaway ramp at the measured breakaway plus 2%.

Raising the duty on a shaft that is not moving is exactly what a jam should not get, so a raise is allowed in two places only. Resting clear of the stops, 300 counts or more from both (or anywhere while the stops are unknown), a raised duty meets nothing but the mechanism's own friction. Leaving a stop, starting within 150 counts of one and pointing away, the step is 5%, because breaking out of a stop costs more than holding one. Anywhere within 300 counts of a stop, driving toward it or resting between 150 and 300 counts from it, the duty is fixed.

A shaft still at the cap, still after it has travelled, still where no raise is allowed, or held by the firmware's stall fold is blocked, and the whole run ends there with torque off. With the stops unknown the check first tries the other direction once. The same rule governs every seek in a run: a seek that comes to rest is at a stop only when it rests within 150 counts of the stop it was driving at (with the stops unknown, only after 100 counts of travel). Anywhere else it is a jam or a pot that is not reading, which look the same to a seek that judges by stillness, and the run ends. A blocked shaft is not centred afterwards. Nothing drives it again.

What bounds the check itself: under the window floor the limiter is blind, but the stall current there is at most $d_\text{floor}\cdot V_\text{bus}/R$, the blind band above, 0.214 A for the MG90 winding on 7.9 V. From the floor up the limiter holds the limit whatever the duty, and the stall timer ends a blocked check (How the Stall Timer Sees It, above), as a stall fault or as the yield fold the check reads as blocked. The check never holds the permit. On 2S, from the class-safe 9.5% to the 25.3% cap is at most six raises over seven still windows.

#### The Burst Allowance

Winding $R$ and $L$ come next, because every stall-safe duty after them is planned from $R$, and they come from the high-rate shunt burst. A burst runs over the static limit on purpose: the fit needs from-rest steps at 25% and at a second duty at least 10 points above it, and on 2S the 25% step alone would stall the bench MG90 at about 450 counts against its 280.

That is acceptable because of what the limit protects against. The 0.30 A damage figure is a sustained torque into a blocked output. A burst drives the winding for about half a millisecond from rest, then the first kernel tick replaces the step. In that time the rotor turns a fraction of the gear lash and carries a small fraction of the energy an ordinary seek gives it, so the load it bounds is the rotor's momentum, not a held torque. The bound is therefore in volts applied, a class figure, and not a multiple of the user's limit. The allowance, as the host holds it:

- The jam check proved the shaft free in this run. No burst arms before it.
- The shaft sits in the band at mid travel, at rest, or at the class-safe duty for the one from-a-hold control step.
- The applied volts are at most 3.2 V. The two rungs are 25% and the lower of 40% and 3.2 V over the rail, in whole percent: 25% and 40% at 7.9 V and at 4.39 V, 25% and 38% at 8.4 V. Over 9.1 V the pair falls under 10 points apart and the run stops before anything arms.
- At most 24 arms a run, and a rung whose settled current, predicted from the rungs already captured, would clear 3.2 V over 3.0 ohm, 1.07 A, is dropped.
- Never seated and never with the permit. The one exception is the held route, asked for by name (`osc ident burst --burst-stops`), whose hold and steps are stall-safe by duty.

The firmware enforces the volts, the 100 ms spacing and the position at the arm (What It Does Not Cover, below), so a host that ignores all of this still gets no more than that.

A burst that declines ends the default run, because nothing after it can be planned. Asked for (`osc ident run --stall-ladder`, or `osc ident resistance` on its own), the resistance stop ladder measures $R$ instead, stalling each stop at up to four dwells between the window floor and the stall-safe cap with the permit held. Its fit takes the terminal voltage as well as the current, so its floor is the higher of the two the servo publishes; on osc-dev-v006 that is the terminals' 7.7% over the current's 5.3% (13.3% for the terminals under Fast decay). It needs at least three dwells 0.5% apart whose stall currents span 15% of the limit; against a 13.3% terminal floor on 2S at a 280-count limit the band to 15.5% spans 14%, so the run refuses before anything moves. On USB the same ladder dwells at 13.3, 18.2, 23.0 and 27.9%.

#### The Runway

A free-running rung starts from rest in a 75-count band at one end of the travel guard and runs toward the other end. It climbs to speed on the current limit, settles, collects its steady windows, and brakes. It runs only when all of that fits:

$$\text{need}(d) = \frac{v^2}{2a} + v\cdot t_\text{win} + 1.25\cdot s(v) \le \text{room}$$

The room is the guard span less the start band. $v$ is the steady speed at duty $d$, $a$ the acceleration of a governed climb, $t_\text{win}$ the time the settle and steady windows take, and $s(v)$ the distance the shaft takes to stop from $v$. Speed and stop come from a pilot envelope (`osc capture pilot`) when one describes this servo: measured on the same supply, with both physical stops within 150 counts of the servo's, holding at least one coast. Then $v$ is the envelope's steady-speed line and $s$ the coast law $s = c_1 v + c_2 v^2$ fitted over every coast the pilot measured. Without one the run sizes itself from what it has measured: the speed from the line through the last two measured rungs (one point scales in proportion to duty, and a prediction never falls under a speed already measured at or under that duty), the stop from the last braked stop scaled by speed squared above it and in proportion below it, and $a$ from the last governed climb, 40 counts/ms per second before one is measured. The first rung is sized from the seek that carried the shaft to its start. Every drive ends braked, a seek as it arrives in the start band and a rung at its brake point, the far guard less $1.25\cdot s(v)$, with the brake idiom: a token duty of 82 in Q15 against the motion, which under slow decay shorts the winding through the bridge. A zero duty would coast.

The ladder climbs from the bottom, and the first rung whose need does not fit ends it. On the bench MG90 with its 2S pilot envelope the room is 2919 counts (soft limits 432 to 3626), and the coast law puts 26% at 457 counts, 40% at 992 and 64% at 2350: the default rungs, 26 to 64%, all fit. 80% would need 3564 and 100% 5431, so on this servo's travel neither fits, and a ladder asked to climb past 64% ends there. A ladder with fewer than three rungs run both ways, or whose top speed is under twice its bottom one, is declined rather than fitted thin. A rung still governed after twice its predicted climb is a blocked shaft when the shaft is still, and otherwise declines the ladder: the load is too heavy for the current limit. Cal's ripple traverse takes the same rule at 26%, inside a guard 150 counts in from the stops it just found, and a traverse the run cannot size does not run.

Inertia takes the runway too, from a moving base. From rest, the steps the limit leaves room for sit inside a servo's breakaway, so they may not move the shaft at all. Running, friction is already paid. The base is the seek duty plus 5%, its running current $i_\text{run}$ is read, and the steps over it are 0.5, 0.75 and 1.0 of the clean-step headroom above, $(\frac{7}{8} i_\text{lim} - i_\text{run})\cdot R/V_\text{bus}$. For a shaft that breaks away at 8%, seeks at 10% and runs a 15% base at 80 counts, that is 9.1% on 2S and steps to 19.5, 21.8 and 24.1%, and on USB steps to 23.2, 27.3 and 31.5%. Each step is one TEL burst whose goal write and capture arm commit together, and the fit takes the applied duty the burst reports. A base or step whose need does not fit is skipped, and a base that does not travel, or that the stall timer folds, ends the run blocked.
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

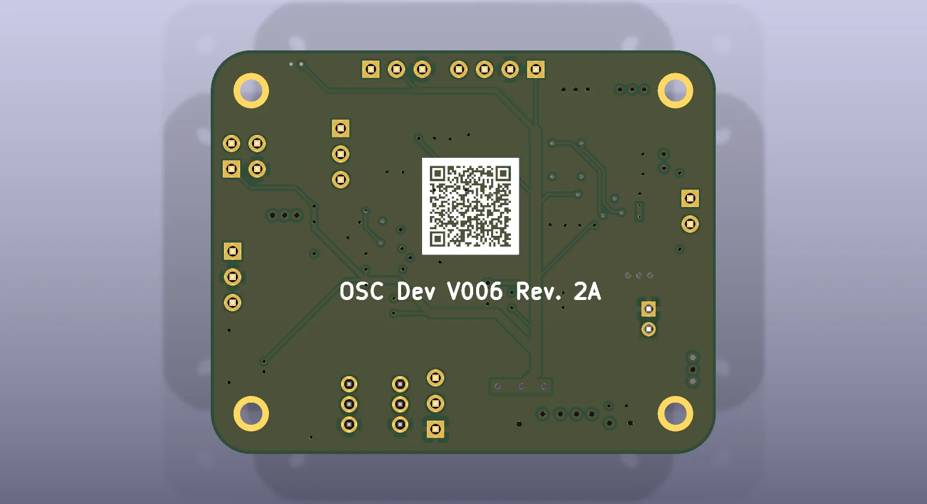
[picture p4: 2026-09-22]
hardware/boards/osc-dev-v006/docs/back.webp

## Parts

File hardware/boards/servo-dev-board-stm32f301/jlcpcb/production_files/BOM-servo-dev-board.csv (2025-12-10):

Comment | Designator | Footprint | LCSC | Quantity
0.1uF | C1,C2,C3,C6,C7 | C_0402_1005Metric | C1525 | 5
10nF | C9 | C_0402_1005Metric | C15195 | 1
12pF | CL1,CL2 | C_0402_1005Metric | C1547 | 2
16MHz 9pF | Y1 | Crystal_SMD_3225-4Pin_3.2x2.5mm | C13738 | 1
1K5 | R7 | R_0402_1005Metric | C25867 | 1
1kΩ@100Mhz | L1 | L_0402_1005Metric | C76883 | 1
1uF | C10,C4,C5 | C_0402_1005Metric | C52923 | 3
22uF | C11 | C_0603_1608Metric | C59461 | 1
4.7uF | C8 | C_0603_1608Metric | C19666 | 1
4K7 | R1,R2,R3,R4,R5,R6 | R_0402_1005Metric | C25792 | 6
Conn_01x04_MountingPin | J3,J4 | JST_SH_BM04B-SRSS-TB_1x04-1MP_P1.00mm_Vertical | C160390 | 2
Conn_01x05_MountingPin | J2 | JST_ZH_B5B-ZR-SM4-TF_1x05-1MP_P1.50mm_Vertical | C265440 | 1
Conn_01x08_Pin | H1,H2 | PinHeader_1x08_P2.54mm_Vertical | C6332201 | 2
Conn_02x05_Odd_Even | J5 | IDC-TH_10P-P1.27-X1270WV-2X05A-6TV01 | C2962225 | 1
DRV8231ADSGR | U1 | WSON-8-1EP_2x2mm_P0.5mm_EP0.9x1.6mm | C5139865 | 1
RED | LED1 | LED_0603_1608Metric | C2286 | 1
SSP7615-33DFR | U2 | UDFN-4-1EP_1x1mm_P0.65mm_EP0.48x0.48mm | C3011523 | 1
STM32F301K8Ux | U3 | QFN-32-1EP_5x5mm_P0.5mm_EP3.45x3.45mm | C111684 | 1
SW_Push | SW1,SW2 | SW_SPST_PTS810 | C221895 | 2
USB_B_Micro | J1 | USB_Micro-B_Amphenol_10118194-0001LF_Horizontal | C428495 | 1

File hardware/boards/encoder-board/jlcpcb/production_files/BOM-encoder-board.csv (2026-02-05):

Comment | Designator | Footprint | LCSC | Quantity
100nF | C1,C2 | C_0805_2012Metric_Pad1.18x1.45mm_HandSolder | C28233 | 2
10uF | C3 | C_0805_2012Metric_Pad1.18x1.45mm_HandSolder | C15850 | 1
390 | R2,R4 | R_0805_2012Metric_Pad1.20x1.40mm_HandSolder | C17655 | 2
680 | R1,R3 | R_0805_2012Metric_Pad1.20x1.40mm_HandSolder | C17798 | 2
Conn_01x04 | J1 | PinHeader_1x04_P2.54mm_Vertical | C2905435 | 1
ITR1204SR10A_TR(BY) | U1,U2 | OPTO-SMD-4_ITR1204SR10A | C475373 | 2

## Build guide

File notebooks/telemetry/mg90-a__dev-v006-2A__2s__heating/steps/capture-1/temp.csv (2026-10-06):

t_s | unix | phase | can_c | ntc_raw | vbus_raw | rail_v | heat_i_rms_a | heat_i_absmean_a | heat_p_w | period_ms | duty_applied_absmean_pct
9.9 | 1791273455.5 | prewait | 28.7 | 1851 | 1907 | 7.682
14.9 | 1791273460.6 | prewait | 28.6 | 1859 | 1915 | 7.714
20.0 | 1791273465.6 | prewait | 28.5 | 1860 | 1914 | 7.71
25.0 | 1791273470.7 | prewait | 28.5 | 1851 | 1906 | 7.678
30.1 | 1791273475.8 | prewait | 28.4 | 1850 | 1905 | 7.674
35.2 | 1791273480.8 | prewait | 28.3 | 1851 | 1905 | 7.674
40.2 | 1791273485.9 | prewait | 28.2 | 1862 | 1915 | 7.714
45.3 | 1791273491.0 | prewait | 28.2 | 1854 | 1909 | 7.69
50.4 | 1791273496.1 | prewait | 28.1 | 1851 | 1902 | 7.662
55.4 | 1791273501.1 | prewait | 28.0 | 1853 | 1905 | 7.674
60.5 | 1791273506.2 | prewait | 28.0 | 1851 | 1903 | 7.666
65.6 | 1791273511.3 | prewait | 27.9 | 1862 | 1915 | 7.714
70.6 | 1791273516.3 | prewait | 27.9 | 1853 | 1905 | 7.674
75.7 | 1791273521.4 | prewait | 27.8 | 1853 | 1904 | 7.67
80.8 | 1791273526.5 | prewait | 27.8 | 1851 | 1901 | 7.658
85.9 | 1791273531.5 | prewait | 27.7 | 1851 | 1902 | 7.662
90.9 | 1791273536.6 | prewait | 27.7 | 1855 | 1906 | 7.678
96.0 | 1791273541.7 | prewait | 27.6 | 1861 | 1911 | 7.698
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

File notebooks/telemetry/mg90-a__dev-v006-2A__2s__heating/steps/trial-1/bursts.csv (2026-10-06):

k | phase | t_s | unix | can_c | vbus_raw | rail_v | wave_r_ohm | wave_r_sd_ohm | l_mh | v0_v | slope_ohm | v_over_i_ohm | verdict | t_from_r | t_minus_can | dir
0 | heat0.3W | 70.5 | 1791273108.1 | 28.3 | 1907 | 7.682 | 4.885 | 0.044 | 0.785 | -0.176 | 5.256 | 4.841 | declined | 35.06 | 6.76 | 1791273108

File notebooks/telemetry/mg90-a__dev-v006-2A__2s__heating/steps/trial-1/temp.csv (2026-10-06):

t_s | unix | phase | can_c | ntc_raw | vbus_raw | rail_v | heat_i_rms_a | heat_i_absmean_a | heat_p_w | period_ms | duty_applied_absmean_pct
10.1 | 1791273047.7 | heat0.3W | 26.8 | 1855 | 1902 | 7.662 | 0.0 | 0.0 | 0.0 | 250 | 0.0
15.2 | 1791273052.7 | heat0.3W | 26.8 | 1855 | 1907 | 7.682 | 0.1605 | 0.1379 | 0.122 | 225 | 12.1
20.2 | 1791273057.7 | heat0.3W | 26.8 | 1857 | 1907 | 7.682 | 0.1756 | 0.1533 | 0.146 | 182 | 13.0
25.2 | 1791273062.7 | heat0.3W | 26.9 | 1855 | 1883 | 7.585 | 0.1875 | 0.1666 | 0.166 | 148 | 13.8
30.2 | 1791273067.7 | heat0.3W | 27.0 | 1853 | 1904 | 7.67 | 0.1875 | 0.1682 | 0.166 | 133 | 13.9
35.2 | 1791273072.7 | heat0.3W | 27.1 | 1856 | 1906 | 7.678 | 0.1772 | 0.1581 | 0.148 | 108 | 13.0
40.2 | 1791273077.7 | heat0.3W | 27.2 | 1852 | 1901 | 7.658 | 0.186 | 0.1656 | 0.163 | 87 | 12.8
45.2 | 1791273082.8 | heat0.3W | 27.4 | 1853 | 1882 | 7.581 | 0.1963 | 0.1799 | 0.182 | 80 | 12.6
50.3 | 1791273087.8 | heat0.3W | 27.5 | 1853 | 1889 | 7.609 | 0.1988 | 0.1828 | 0.187 | 80 | 13.3
55.3 | 1791273092.8 | heat0.3W | 27.6 | 1851 | 1880 | 7.573 | 0.1946 | 0.1783 | 0.179 | 80 | 12.1
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

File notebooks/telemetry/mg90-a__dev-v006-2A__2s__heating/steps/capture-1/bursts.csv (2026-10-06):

k | phase | t_s | unix | can_c | vbus_raw | rail_v | wave_r_ohm | wave_r_sd_ohm | l_mh | v0_v | slope_ohm | v_over_i_ohm | verdict | t_from_r | t_minus_can | dir
0 | ref | 162.3 | 1791273608.0 | 27.15 | 1902 | 7.662 | 4.722 | 0.042 | 0.786 | -0.159 | 5.093 | 4.750 | declined |  |  | 1791273607
1 | ref | 228.3 | 1791273674.0 | 27.0 | 1914 | 7.71 | 4.69 | 0.045 | 0.768 | -0.127 | 5.059 | 4.850 | declined |  |  | 1791273674
2 | ref | 294.2 | 1791273739.9 | 26.85 | 1914 | 7.71 | 4.582 | 0.044 | 0.754 | -0.042 | 4.951 | 5.041 | PROMOTED |  |  | 1791273739
3 | heat0.4W | 481.5 | 1791273927.2 | 33.45 | 1907 | 7.682 | 5.009 | 0.047 | 0.771 | -0.116 | 5.384 | 5.189 | declined | 44.79 | 11.34 | 1791273927
4 | heat0.4W | 622.5 | 1791274068.2 | 36.25 | 1905 | 7.674 | 5.278 | 0.051 | 0.799 | -0.196 | 5.653 | 5.167 | declined | 59.79 | 23.54 | 1791274068
5 | heat0.4W | 764.0 | 1791274209.7 | 37.75 | 1899 | 7.65 | 5.299 | 0.057 | 0.783 | -0.141 | 5.679 | 5.400 | declined | 60.96 | 23.21 | 1791274209
6 | heat0.4W | 905.4 | 1791274351.0 | 38.75 | 1897 | 7.642 | 5.663 | 0.069 | 0.799 | -0.248 | 6.050 | 5.375 | declined | 81.25 | 42.5 | 1791274351
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

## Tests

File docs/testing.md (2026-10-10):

# Testing: the three gears

The transport is verified by three test gears, each proving something the others
structurally cannot. Green across all three — `scripts/gears.sh` — is what lets
us pronounce the tree good.

| gear | proves | where | gate |
|---|---|---|---|
| **1 — unit** | the pieces are individually correct: codec, CRC vectors, control-table rules, driver internals | in-crate `#[cfg(test)]` across `firmware/lib/*` and `tools/bench` | CI |
| **2 — DES** | the pieces compose correctly under adversarial sequencing, at every baud, deterministically | `firmware/lib/integration` (discrete-event sim) | CI |
| **3 — bench** | the real silicon meets timing and survives zero-gap load under real ISR/DMA/drift | `tools/bench/tests/hardware` (hardware-in-the-loop) | on-rig |

The division of labour is deliberate. **Gear 2 is wide but blind to time**: the
sim dispatches with a *zero* CPU-time model, so it proves logical correctness and
sequencing at every baud but cannot see ISR latency, wall-clock turnaround, HSI
drift, or the frame-N-deadline-vs-frame-N+1-break window. **Gear 3 is the deep-
on-timing, narrow-on-logic gear**: its whole job is the silicon-only failure
modes gear 2 erases. So for every property the sim is structurally blind to,
gear 3 carries one hardware assertion with a measured budget — it is complete on
silicon-only properties, not on logic.

## Running

```sh
scripts/gears.sh
```

Gears 1 and 2 are deterministic and need no hardware. Gear 3 needs an
osc-adapter with a flashed V006 on its bus; the script auto-detects the adapter
by its USB identity and **skips** gear 3 (rather than failing) when no rig is
attached. Force-skip with `SKIP_BENCH=1`; force-run with `BENCH_FORCE=1`. The
suite targets servo id 1 at the 1 M boot baud by default; override with
`BENCH_ID` / `BENCH_BAUD`.

The gears map to plain cargo invocations if you want to run one directly:

```sh
( cd firmware/lib && cargo test --workspace )            # gear 1 + 2
( cd tools/bench  && cargo test --lib )                  # gear 1 (bench units)
( cd tools/bench  && cargo test --test hardware -- --test-threads=1 )   # gear 3
```

## Torque limit pins

The OpenLoop duty limiter, the stall permit lease and the class default
limits (control-theory "Limits", protocol sec 5.8) are pinned in gears 1
and 2. The DES pins run the kernel against the MG90-scale R-L plant rig
(`integration/src/plant.rs`: 4.9 ohm winding, 7.9 V rail), so they
read the winding current the limiter only sees through the shunt window
one tick late. Unless a pin says otherwise the limit is 280 counts and
the goal is 64% duty, in both directions. Paths below are under
`firmware/lib`.

The limiter law (`core/src/kernel/duty_limit.rs`):

- `blind_goal_passes_raw` - a goal at or under the window floor comes
  back unchanged at any current, a zero limit included.
- `ceiling_rises_at_the_up_rate_from_the_floor` - below the band the
  ceiling climbs 128 per tick from the floor and stops at the goal.
- `ceiling_holds_inside_the_band` - current from `lim - lim/8` up to
  `lim` leaves the ceiling where it is.
- `ceiling_drops_by_the_overage` - 10 counts over drops the ceiling by
  80 and records a pin.
- `goal_cut_applies_at_once` - a lowered goal lands the same tick;
  raised again, it slews from the cut.
- `zero_limit_never_rises` - a zero limit neither rises nor underflows.
- `ceiling_under_the_floor_applies_the_base` - under the floor the base
  applies, never above the goal, and the rise back past the floor is
  the re-probe.
- `slew_alone_is_never_pinned` - neither a slew nor a hold at the goal
  pins, only a ceiling held under the goal does, and taking the pin
  clears it.

The floor, the observer and the defaults (`core/src/estimator/window.rs`,
`fusion.rs`, `core/src/regions/config.rs`):

- `floor_duty_is_window_valid` - the floor duty clears the current
  window for floors of 100, 160 and 240 ticks; 160 of 1200 is 4356.
- `floor_duty_is_the_smallest_valid_duty` - one Q15 step less misses
  the window, for every floor up to 1200 ticks, and up to 512 at five
  other periods.
- `floor_duty_saturates_past_full_duty` - a floor past the period asks
  for full duty.
- `fast_decay_takes_the_higher_trough_floor` - Slow decay's terminal
  floor is CALIB's alone, Fast decay's the higher of it and the board's
  trough floor.
- `bemf_floor_voids_the_observer_and_keeps_the_differential` - a window
  one tick under the board's back-EMF floor leaves the back-EMF velocity
  at 0 while the terminal differential still lands; at the floor the
  boxcar reads its pinned value.
- `unset_model_holds_tau_d_at_zero` - with the motor model unset, a
  driven and moving shaft never moves tau_d off zero while theta still
  tracks.
- `arm_b_rig_reproduces_the_count_seeds` - the class defaults land as
  184 / 111 / 55 / 184 / 1352 / 92 counts on the 33 mohm chain.
- `current_counts_scales_with_the_shunt_and_saturates` - 300 mA is 335
  counts on the 60 mohm chain.

The current the limiter reads (`core/src/estimator/window.rs`,
`core/src/kernel/tests.rs`):

- `settle_gain_bands_start_at_their_edge` - each 8-tick band takes its
  gain from its first tick to its last.
- `settle_gain_clamps_below_and_is_unity_above` - a window under the
  first band takes the first band, one past the last band and every
  window of an empty table read at unity.
- `current_gain_rounds_and_keeps_the_sign_symmetric` - 300 counts at
  33259 read 304 in both drive signs, rounded half up.
- `current_unity_gain_is_exact` - unity returns the bias-subtracted
  sample unchanged over the whole u16 range.
- `settle_gain_lifts_a_short_window_and_leaves_the_raw_sample` - a
  100-tick OpenLoop window reads 304 for 300 counts in the stream's
  `current` while `current_raw` stays raw; past the table it reads 300.

The lease and the flags (`core/src/kernel/tests.rs`,
`core/src/services/bus/tests/mod.rs`):

- `permit_lease_expires_without_a_host` - one write opens the endstop
  for 0.99 to 1.01 s, then it stays closed; the kernel never clears the
  request byte.
- `permit_rewrite_extends_the_lease` - a rewrite at 0.8 s runs the
  lease a second from the rewrite, and a write of false revokes inside
  one medium tick.
- `torque_off_drops_the_permit` - torque off ends the lease, and
  re-enabling inside the second does not revive it.
- `permit_written_with_torque_off_never_grants` - a request written
  under torque off grants nothing once torque comes back on.
- `limit_flags_name_the_governor` - each bit alone: ceiling in OpenLoop,
  yield after a Current-mode stall, endstop past a soft wall, permit
  with the endstop dropped.
- `permit_write_bumps_the_generation_only_when_set` - only a committed
  true with torque on grants; a torque-off request, false, a span that
  misses the byte and a staged HOLD write do not, and one span over
  torque and permit is judged as committed.

The limiter on the plant rig (`integration/tests/torque_limit.rs`):

- `openloop_locked_rotor_mid_travel_holds_at_i_lim` - 2 s on a locked
  rotor: peak within 1.1x the limit, mean after the first 100 ms within
  0.85x to 1.0x, no fault.
- `openloop_stall_holds_at_i_lim` - the same, seated on a hard stop
  inside the soft limits.
- `openloop_first_edge_stays_under_i_lim` - 0 to 100% on a locked rotor
  peaks within 1.05x the limit over the first 20 ms.
- `openloop_ceiling_releases_when_the_shaft_frees` - a governed 40% goal
  is back at the goal within 100 ms of the shaft freeing and stays
  there.
- `openloop_blind_goal_is_untouched` - a 12% goal under the floor
  applies exactly, from the first tick, on a locked rotor.
- `openloop_reversal_restarts_from_the_floor` - reversing out of a held
  64% restarts at the floor and never outruns the 128-per-tick slew.
- `openloop_wall_hit_at_speed_recovers_inside_1ms` - a stop hit above
  1000 counts/s is over 1.1x the limit only within the first
  millisecond, no fault.
- `openloop_stall_yields_like_closed_loop` - Yield response: the limit
  folds to the yield value no sooner than `stall_time_ms` and within
  100 ms after it, and stays folded on every tick of the next second.
- `openloop_stall_faults_on_the_boot_response` - Fault response: STALL
  latches in the same window and the drive disables.
- `openloop_slew_never_counts_as_a_stall` - with a 1 ms stall timer, a
  blind start and a slew to 64% across the travel never trip.
- `openloop_stall_under_permit_never_trips` - a permit rewritten every
  250 ms holds a locked rotor at the limit for 2 s with no fold and no
  fault.
- `dead_host_stall_trips_within_the_lease` - one permit write, then
  silence: STALL latches 1.5 to 1.6 s after it.
- `blind_band_caps_at_i_lim_when_r_is_known` - a limit of 200, under the
  floor's 239-count stall current: most ticks sit under the floor, each
  at a duty stalling at 95 to 100% of the limit, mean within 1.1x.
- `yield_fold_reaches_the_blind_band` - after a fold to a yield of 168
  the blind band holds the yield the same way for the whole second
  after it, mean within 1.2x.
- `virgin_blind_band_passes_to_the_window_floor` - with `r_q12` at 0
  the duty never goes under the floor and sits there pinned, at the
  floor's stall current.
- `window_floor_is_published_as_the_limiter_uses_it` - for 160 and 240
  ticks the published `window_floor_q15` is `floor_duty` of the board's
  period, and the duty a virgin stall pins at equals it.
- `window_v_floor_is_published_beside_the_current_floor` - at 64 and
  160 ticks the two published floors read 1734 and 4356, and a
  `v_window_min_ticks` rewrite shows within one medium tick, torque off.
- `window_v_floor_follows_the_openloop_decay` - with a 93-tick CALIB
  floor and a 160-tick trough floor, Slow OpenLoop publishes the duty of
  93 and Fast the duty of 160.

A virgin servo (`integration/tests/class_defaults.rs`, boot seed on the
60 mohm chain):

- `virgin_openloop_run_never_collision_trips` - free runs at +/-64%, 30%
  and 0 raise no fault and leave tau_d at zero.
- `virgin_servo_stalls_at_the_class_limit` - locked at 64%, it holds at
  the 335-count class limit: peak within 1.1x, mean 0.85x to 1.0x, no
  fault inside the stall time.

## Identification and calibration pins

How `osc ident` and `osc cal` plan their drives under the current limit
(control-theory "Open Loop Under the Same Band" and "Calibration",
protocol sec 5.8) is pinned in the host crates' own unit tests: `ident`
and `tools/osc` at the repo root, each `cargo test` in its directory
and in CI. The drives run against a fake servo that models the limiter,
the stall timer and fold, the permit lease and the burst; the bench
MG90 on it is a 4.9 ohm winding, a 280-count limit, the 13.3% window
floor, stops at 209 and 3849 and soft limits at 432 and 3626, on a 2S
rail of 3204 vcounts or a USB rail of 1780. Paths below are under
`ident/src` unless they say otherwise.

The servo's limits and the stall-safe plan (`limits.rs`):

- `servo_limits_take_the_floor_from_the_servo` - the limits carry the
  floor a telemetry read publishes, 4356 and 6534 alike, and the stop
  ladder starts on it.
- `a_differential_fit_plans_from_the_higher_floor` - with the current
  floor at 1734 and the terminal floor at 4356 the stop ladder starts
  on 4356 and on 2S has no room, though the current alone would; a
  terminal floor of 0 leaves the current floor.
- `a_servo_without_a_floor_is_refused_in_plain_words` - a published 0
  refuses with a message naming the missing sensor floor; no board
  constant stands in.
- `board_default_limits_are_refused` - soft limits that span the pot, or
  are out of order, refuse with "run `osc cal` first".
- `guards_come_from_the_soft_limits` - the travel guard sits 100 counts
  inside each soft limit, each end overridable alone.
- `i_abort_defaults_a_quarter_over_the_current_limit` - 350 at a limit
  of 280; lower is taken, higher is refused in plain words.
- `every_stall_safe_duty_stalls_under_the_limit` - seek, hold and stop
  cap stall at or under the limit however they are rounded, over five
  limit and rail pairs; on 2S the cap is 15.5%, the hold 7.76% and a
  step over an 80-count base 9.1%.
- `bootstrap_duty_is_class_safe` - the class-safe duty is 9.5% at the
  bench limit on 2S and stalls at the limit on a 3.0 ohm winding; on
  USB it applies the same volts.
- `plan_over_the_limit_is_refused_in_plain_words` - a deliberate stall
  over the limit names the duty, the current and the highest duty the
  limit holds.
- `stall_ladder_rungs_stay_under_the_limit` - every stop-ladder dwell
  sits between the window floor and the stall-safe cap, 0.5% apart.
- `the_stop_ladder_needs_room_over_the_window_floor` - on 2S at 280 the
  band from 13.3% to 15.5% is refused; on USB it dwells at 13.3, 18.2,
  23.0 and 27.9%.
- `burst_rungs_fit_the_fit_and_the_allowance` - 25/40% at 7.9 and
  4.39 V, 25/38% at 8.4 V, 25/35% at 9.1 V, none above it; every top
  rung at most 3.2 V.
- `burst_count_is_bounded` - repeats are cut so a run arms at most 24.
- `the_lease_is_held_only_behind_torque_on` - a permit written with
  torque off is not held, a held one is due every 250 ms, torque off
  drops it, and a stream over 750 ms with it held is refused.
- `stall_settings_above_the_limit_are_warned` - a yield not under the
  limit and a collision trip over twice it are warned in plain words.

The run order and cal's sequence (`run.rs`):

- `run_all_stops_at_the_first_abort` - an abort at any stage ends the
  run there; a declined burst ends it, a declined ladder still ends
  with the closing centring.
- `default_run_never_stalls_a_stop` - the whole default run on both
  rails, and on a rail too high for the burst, never presses a stop and
  never writes the permit.
- `burst_waits_for_the_nudge` - no burst before the jam check moved the
  shaft, and none at 9.4 V.
- `nudge_cap_is_two_volts_on_the_rail` - class-safe start 9.5% and cap
  25.3% on 2S, 17.1% and 45.6% on USB.
- `burst_cfg_is_the_allowance` - 25/40% from rest, the from-a-hold
  control from the class-safe duty, repeats cut to the arm count.
- `bench_mg90_run_reaches_the_fit_on_2s_and_usb` - R and L from the
  burst, a ladder of three or more rungs, an inertia fit, at most 24
  arms, ending near mid travel with torque off.
- `r_and_l_are_measured_before_any_planned_drive` - before the burst
  nothing exceeds the jam check's cap or the 3.2 V allowance; after
  it, every stall-safe drive stays at or under the stop cap.
- `bench_inertia_base_and_steps` - seek 10%, base 15%, steps to 19.5,
  21.8 and 24.1% on 2S and 23.2, 27.3 and 31.5% on USB.
- `virgin_run_escalates_the_nudge_and_measures_r` - a shaft that needs
  more than the class-safe duty is raised until it moves, then the
  burst measures R.
- `a_mid_travel_jam_ends_the_run_at_the_first_seek` - a locked shaft
  ends the run in the jam check, at or under its cap, with no burst and
  no stream.
- `the_stop_ladder_runs_only_on_request` - a declined burst ends the
  run unless asked; asked, on 2S at 280 it refuses for want of room,
  on USB it runs in the burst's place.
- `the_stop_ladder_starts_where_the_terminals_read` - at floors of 1734
  and 4356 the run's first dwell is 4356; with no terminal floor
  published it is 1734.
- `the_stop_ladder_measures_r_when_asked` - on USB, both stops stalled
  over the floor and under the limit with the permit held, R within
  2%, the run planned from it to the end.
- `cal_order_and_its_ends` - bias, jam check, burst, stops, traverse,
  centring; a declined burst or a high rail goes on without R, an
  abort ends where it stands.
- `cal_duties_on_the_bench_servo` - a shaft that moved at 13%
  approaches at 15% on both rails and seats at 7.76% on 2S and 14.0%
  on USB, half the limit.
- `cal_approaches_at_the_duty_that_moved` - moved at 14.5% on 2S, the
  approach is capped at the stop cap; at 17.1% on USB it is 19.1%; the
  permit is held only while the stops are found.
- `cal_finds_the_stops_on_a_virgin_servo` - no stops or soft limits
  known: the same run finds 209 and 3849 and ends at mid travel.
- `cal_never_escalates_toward_a_stop` - toward a stop only the approach
  duty, the seat duty and 0 are ever written; the traverse's first pass
  and the closing centring run at the approach duty.
- `cal_refuses_when_breakaway_is_over_the_limit` - moved at 17% on 2S,
  307 counts over 280: refused before any stop drive, no permit
  written.
- `cal_without_r_seats_at_the_class_half_duty` - the burst declined:
  approach at the moving duty, seat at 4.76% on 2S.
- `cal_on_a_jammed_shaft_writes_nothing` - a locked shaft ends cal in
  the jam check; only drive fields in CONTROL were ever written.

The runway (`runway.rs`):

- `room_is_the_guard_less_the_start_band` - 2919 counts on the bench
  guard, start band edges and brake points as the rule places them.
- `bench_mg90_runway_fits_the_rungs_to_64_and_not_100` - with the 2S
  pilot envelope, 26% needs 457, 40% 992, 64% 2350 and fit; 80% 3564
  and 100% 5431 do not.
- `stale_envelope_is_ignored` - an envelope of another supply, with a
  stop more than 150 counts off, or without a coast sizes nothing.
- `self_sizing_follows_the_measured_rungs` - one speed scales in
  proportion, two make a line, a stop scales by speed squared above
  and in proportion below.
- `coast_falls_back_to_the_measured_runs` - the coast law fits the
  bench coasts; one coast scales by speed squared.
- `need_adds_climb_run_and_a_margined_stop` - need is the climb, the
  run and 1.25 stops, and a zero acceleration never fits.

Stops and stillness (`exp/seek.rs`):

- `a_mid_travel_rest_is_not_a_stop` - a rest is a stop only within 150
  counts of the stop driven at; with the stops unknown, only after 100
  counts of travel.
- `clear_of_the_stops_is_300_counts_from_both` - the raise zone starts
  300 counts in from each stop.
- `only_a_drive_off_a_stop_leaves_it` - within 150 counts of a stop and
  pointing away; never with the stops unknown.
- `stillness_is_net_travel_over_a_window` - jitter is not travel, and a
  turn inside a window is not a rest.

The jam check (`exp/centre.rs`):

- `a_centred_shaft_is_left_alone_unless_nudged` - a centred shaft gets
  no write; with the check asked for it goes out and back at the start
  duty.
- `nudge_raises_the_duty_only_clear_of_the_stops` - raised 2.5% per
  still window at mid travel and held at first travel; 250 counts from
  a stop it is blocked, never raised.
- `nudge_gives_up_at_the_cap` - a locked shaft is raised to the cap,
  never over, and ends blocked.
- `a_yield_fold_ends_the_nudge_blocked` - the firmware's stall fold is
  the verdict at once.
- `slow_seek_is_raised_not_blocked` - a shaft creeping under the
  stillness speed gets a raise, not a verdict.
- `unknown_stops_try_the_other_direction` - with no stops known, a
  still check tries the other way once.

Cal's stop finder (`exp/endstop.rs`):

- `cal_seats_at_half_the_limit_after_backing_down` - approach, seat,
  hold 300 ms, the stop is the mean of the last 8 polls, then leave;
  the permit held throughout and withdrawn at the end.
- `recal_rides_a_sticky_spot_under_the_cap` - a mid-travel sticky spot
  raises the approach under the cap, and it carries on to the stop.
- `a_sticky_spot_over_the_cap_is_blocked` - the same spot at the cap
  ends blocked.
- `a_blocked_shaft_finds_no_stops` - an approach that never travels
  ends the run, and rests that do not bracket the start 1500 counts
  apart are no stops.

The ladder (`exp/ladder.rs`):

- `free_running_rungs_fit_the_runway` - every rung on both rails sized
  inside the room and braked at its end, the top rung over twice the
  stall-safe duty.
- `ladder_stops_climbing_at_the_first_rung_that_does_not_fit` - with
  the 2S envelope, rungs to 55% run, 80% ends the ladder, and nothing
  at or over it is driven.
- `a_climb_that_never_ends_is_blocked_or_declined` - still governed
  after twice its predicted climb: blocked when still, declined as too
  heavy when moving.
- `a_governed_rung_is_declined_and_the_ladder_goes_on` - a rung with no
  clean window is declined and does not count; the next rung runs.
- `a_yield_fold_on_a_rung_ends_the_run_blocked` - the stall fold ends
  the run inside the climb budget.
- `thin_ladder_is_declined` - two rungs both ways, or a top speed under
  twice the bottom one, declines.
- `abort_threshold_rides_over_a_governed_climb` - a governed climb never
  reaches the abort a quarter over the limit.

Inertia (`exp/inertia.rs`):

- `inertia_steps_from_a_moving_base` - each step leaves the moving base
  and is sized from its running current; none reaches the limit.
- `a_governed_step_is_declined` - a step the limiter holds under its
  goal is declined, never fitted.
- `a_yield_fold_on_the_base_ends_the_run_blocked` - a base held into a
  jam ends the run before any step.
- `inertia_base_and_steps_fit_the_runway` - every base and step sized
  inside the runway, every drive braked.
- `an_inertia_step_that_does_not_fit_is_skipped` - on a short travel
  the larger steps are skipped in plain words and the run goes on.

Cal's traverse (`exp/sweep.rs`):

- `the_guard_sits_inside_the_stops_and_the_soft_guard` - 150 counts in
  from each stop, and inside the soft limits' guard.
- `cal_traverse_brakes_inside_the_stops` - the 26% run is captured and
  brakes inside the guard on both rails, never touching a stop.
- `an_unsized_traverse_does_not_run` - nothing measured and no envelope:
  no run.
- `a_jam_mid_run_is_blocked` - a shaft that locks during the capture
  ends the traverse where it stopped, torque off.
- `a_jam_on_the_way_to_the_start_is_blocked` - so does one locked on
  the way to the start band: blocked, not a start.

Governed windows, the envelope and the permit (`exp/mod.rs`):

- `governed_window_is_declined_never_fitted` - a window held under the
  goal after it was reached never reaches a fit.
- `slew_samples_are_trimmed_not_declined` - a 64% climb from rest is
  trimmed, not counted against the goal.
- `governed_climb_is_trimmed_and_the_settled_windows_fit` - a climb held
  at the limit is trimmed and every settled window fits.
- `a_free_running_governed_climb_fits_only_settled_windows` - the bench
  64% rung hands on only windows at the goal.
- `abort_default_clears_a_held_stall` - a locked shaft held at the limit
  trips an abort at the limit and never the default.
- `permit_follows_torque_on` - the permit is written after every torque
  enable and withdrawn at the end.
- `long_pause_is_sliced_under_the_lease` - a 3 s pause rewrites the
  permit every 250 ms.
- `a_burst_with_dropped_rows_ends_the_run` - a burst the servo dropped
  rows from ends the run torque off before its frames reach the fit; a
  whole one runs to its result.

The stop routes asked for (`exp/resistance.rs`, `exp/held.rs`):

- `a_mid_travel_jam_is_not_a_stop` - a seek that rests short of the stop
  ends the run before any dwell.
- `rung_with_no_clean_window_reports_declined` - dwells the limit holds
  under their duty are declined.
- `pump_refreshes_a_held_permit` - a held run outlasting the lease keeps
  the stop open, every rewrite with torque on.
- `an_abort_mid_burst_still_withdraws_the_permit` - a fault mid run ends
  with duty 0, torque off, permit off.
- `escalation_only_leaves_a_stop` - the duty rises leaving a stop; a
  seek from mid travel stays at the hold duty and aborts.

The burst handshake and the driver (`burst.rs`, `tools/osc/src/rig/pump.rs`):
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

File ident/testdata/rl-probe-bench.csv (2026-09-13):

seg | chain | kind | dir | bias | cmd_duty_q15 | tick | window_valid | pos | duty_q15 | current_raw | vmotor_a | vmotor_b | vbus_raw
0 | 0 | rest | 0 | 0 | 0 | 960 | 0 | 2243 | 0 | 109 | 778 | 783 | 2200
0 | 0 | rest | 0 | 0 | 0 | 961 | 0 | 2245 | 0 | 107 | 779 | 784 | 2201
0 | 0 | rest | 0 | 0 | 0 | 962 | 0 | 2244 | 0 | 111 | 778 | 783 | 2200
0 | 0 | rest | 0 | 0 | 0 | 963 | 0 | 2242 | 0 | 107 | 778 | 782 | 2198
0 | 0 | rest | 0 | 0 | 0 | 964 | 0 | 2244 | 0 | 109 | 779 | 783 | 2200
0 | 0 | rest | 0 | 0 | 0 | 965 | 0 | 2242 | 0 | 109 | 778 | 782 | 2197
0 | 0 | rest | 0 | 0 | 0 | 966 | 0 | 2242 | 0 | 111 | 777 | 781 | 2197
0 | 0 | rest | 0 | 0 | 0 | 967 | 0 | 2242 | 0 | 110 | 778 | 782 | 2197
0 | 0 | rest | 0 | 0 | 0 | 968 | 0 | 2243 | 0 | 108 | 779 | 782 | 2199
0 | 0 | rest | 0 | 0 | 0 | 969 | 0 | 2243 | 0 | 110 | 778 | 783 | 2200
0 | 0 | rest | 0 | 0 | 0 | 970 | 0 | 2243 | 0 | 109 | 778 | 783 | 2200
0 | 0 | rest | 0 | 0 | 0 | 971 | 0 | 2243 | 0 | 108 | 779 | 782 | 2199
0 | 0 | rest | 0 | 0 | 0 | 972 | 0 | 2243 | 0 | 109 | 779 | 784 | 2199
0 | 0 | rest | 0 | 0 | 0 | 973 | 0 | 2242 | 0 | 108 | 778 | 783 | 2198
0 | 0 | rest | 0 | 0 | 0 | 974 | 0 | 2244 | 0 | 108 | 779 | 784 | 2199
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

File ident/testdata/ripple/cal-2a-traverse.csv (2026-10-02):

pos | current
2047 | 89
2047 | 94
2055 | 104
2055 | 103
2047 | 121
2047 | 128
2055 | 133
2055 | 132
2056 | 125
2057 | 117
2058 | 106
2056 | 98
2047 | 92
2047 | 88
2055 | 88
2056 | 85
2057 | 91
2057 | 99
2057 | 112
2056 | 125
2056 | 151
2056 | 137
2057 | 147
2058 | 153
2060 | 151
2060 | 149
2061 | 140
2058 | 130
2057 | 119
2056 | 107
2057 | 100
2058 | 90
2058 | 86
2060 | 87
2060 | 89
2060 | 97
2059 | 106
2057 | 109
2058 | 128
2060 | 133
2060 | 137
2062 | 136
2062 | 128
2062 | 117
2060 | 108
2060 | 100
2059 | 91
2059 | 85
2060 | 83
2061 | 83
2062 | 84
2061 | 92
2060 | 103
2061 | 116
2063 | 113
2062 | 131
2064 | 145
2066 | 149
2066 | 154
2064 | 146
2062 | 139
2061 | 127
2061 | 119
2062 | 107
2064 | 100
2066 | 93
2064 | 87
2065 | 89
2064 | 94
2063 | 101
2063 | 110
2065 | 120
2067 | 118
2069 | 128
2069 | 130
2066 | 130
2063 | 126
2064 | 116
2063 | 112
2065 | 100
2066 | 94
2067 | 86
2067 | 85
2066 | 85
2066 | 88
2066 | 96
2067 | 109
2067 | 117
2068 | 123
2069 | 136
2070 | 147
2069 | 154
2067 | 154
2067 | 150
2068 | 138
2068 | 130
2069 | 119
2069 | 109
2068 | 100
2069 | 88
2068 | 85
2067 | 82
2069 | 85
2071 | 92
2072 | 100
2072 | 119
2073 | 115
2071 | 124
2070 | 130
2068 | 129
2068 | 123
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

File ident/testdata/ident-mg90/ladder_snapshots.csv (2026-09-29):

host_ms | pos | i_mean_counts | vdiff_mean | duty_mean_q15 | agg_seq | omega_bemf_cps
1583.1 | 617 | 240 | 2861 | 8520 | 65412 | 2153
1587.2 | 629 | 218 | 2865 | 8520 | 65417 | 2574
1590.2 | 638 | 187 | 2870 | 8520 | 65420 | 2755
1597.6 | 651 | 184 | 2870 | 8520 | 65424 | 2881
1598.7 | 662 | 153 | 2877 | 8520 | 65430 | 3224
1601.7 | 673 | 151 | 2877 | 8520 | 65433 | 3326
1606.4 | 685 | 131 | 2881 | 8520 | 65438 | 3540
1609.4 | 694 | 141 | 2879 | 8520 | 65442 | 3449
1613.7 | 707 | 128 | 2882 | 8520 | 65447 | 3666
1614.7 | 710 | 120 | 2884 | 8520 | 65448 | 3568
1621.6 | 737 | 116 | 2885 | 8520 | 65456 | 3746
1629.4 | 761 | 115 | 2883 | 8520 | 65459 | 3719
1631.8 | 791 | 104 | 2886 | 8520 | 65468 | 3858
1636.9 | 806 | 112 | 2885 | 8520 | 65471 | 3795
1640.0 | 823 | 98 | 2887 | 8520 | 65477 | 3959
1643.3 | 835 | 93 | 2889 | 8520 | 65481 | 3908
1646.3 | 842 | 101 | 2887 | 8520 | 65484 | 3843
1649.2 | 858 | 103 | 2887 | 8520 | 65487 | 3841
1652.0 | 876 | 98 | 2888 | 8520 | 65490 | 3858
1655.0 | 889 | 103 | 2887 | 8520 | 65493 | 3866
1656.9 | 896 | 96 | 2889 | 8520 | 65496 | 3979
1657.9 | 899 | 104 | 2887 | 8520 | 65497 | 3872
1658.8 | 902 | 95 | 2888 | 8520 | 65498 | 3913
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

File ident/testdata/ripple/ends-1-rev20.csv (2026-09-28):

pos | current_raw
3494 | 116
3491 | 162
3489 | 200
3488 | 248
3488 | 289
3489 | 316
3491 | 339
3492 | 355
3491 | 368
3491 | 379
3490 | 385
3489 | 388
3491 | 390
3492 | 392
3491 | 392
3490 | 394
3490 | 394
3493 | 394
3494 | 395
3491 | 392
3488 | 392
3487 | 389
3490 | 392
3493 | 388
3492 | 390
3490 | 390
3490 | 393
3489 | 392
3491 | 392
3492 | 392
3493 | 391
3489 | 389
3489 | 389
3489 | 392
3492 | 391
3495 | 392
3495 | 393
3491 | 386
3488 | 378
3487 | 376
3490 | 381
3492 | 385
3494 | 385
3494 | 388
3491 | 389
3489 | 388
3488 | 387
3491 | 384
3491 | 381
3491 | 382
3491 | 379
3493 | 380
3492 | 380
3490 | 377
3489 | 373
3489 | 376
3491 | 375
3492 | 373
3492 | 369
3492 | 372
3491 | 376
3491 | 377
3491 | 378
3491 | 377
3489 | 374
3489 | 370
3491 | 365
3495 | 366
3493 | 365
3490 | 367
3489 | 366
3489 | 365
3492 | 364
3494 | 365
3492 | 369
3490 | 371
3490 | 369
3490 | 370
3491 | 365
3492 | 363
3491 | 364
3489 | 360
3494 | 357
3495 | 358
3493 | 361
3491 | 369
3487 | 388
3488 | 402
3490 | 361
3491 | 364
3493 | 366
3492 | 367
3492 | 362
3493 | 363
3491 | 363
3491 | 367
3488 | 372
3492 | 365
3493 | 359
3492 | 361
3490 | 359
3490 | 357
3491 | 358
3493 | 353
3492 | 353
3490 | 351
3489 | 352
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

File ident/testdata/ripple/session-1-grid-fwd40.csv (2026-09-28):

pos | current_raw
491 | 114
491 | 113
491 | 114
491 | 218
491 | 361
490 | 469
492 | 550
491 | 612
491 | 659
490 | 696
490 | 724
491 | 746
490 | 760
491 | 769
491 | 780
491 | 787
491 | 793
490 | 801
490 | 800
491 | 796
490 | 798
490 | 795
490 | 790
490 | 789
491 | 790
491 | 786
492 | 786
491 | 784
491 | 786
490 | 783
490 | 782
491 | 780
491 | 783
490 | 778
491 | 774
492 | 770
491 | 771
490 | 759
490 | 762
490 | 756
492 | 755
492 | 752
492 | 754
491 | 750
491 | 750
491 | 745
490 | 746
491 | 743
491 | 739
491 | 734
491 | 728
492 | 726
491 | 728
490 | 723
491 | 722
491 | 720
491 | 714
492 | 716
490 | 715
491 | 718
490 | 718
491 | 715
490 | 712
491 | 712
492 | 711
491 | 711
491 | 712
490 | 713
491 | 721
490 | 720
491 | 724
491 | 727
491 | 728
492 | 728
491 | 733
490 | 739
491 | 746
491 | 748
491 | 751
490 | 615
491 | 645
491 | 668
492 | 685
492 | 694
491 | 699
492 | 707
492 | 708
492 | 712
492 | 712
491 | 715
491 | 715
492 | 715
492 | 710
492 | 711
492 | 704
492 | 704
492 | 697
493 | 693
492 | 689
493 | 685
494 | 680
494 | 678
493 | 665
493 | 662
494 | 658
496 | 659
497 | 651
499 | 650
499 | 648
500 | 641
502 | 635
503 | 634
505 | 634
505 | 631
507 | 632
509 | 636
509 | 640
510 | 637
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

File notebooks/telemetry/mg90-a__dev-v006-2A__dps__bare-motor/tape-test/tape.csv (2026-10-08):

t_unix | phase | mode | fault | src | omega_hat_q16 | i_lim | t_winding_cc | duty_applied_q15 | omega_bemf | r_hat_q12 | i_hat | sample_tick | pos | current | bias | vbus_raw | i_mean | vdiff_mean | duty_mean_q15 | agg_seq | limit_flags | current_trough | vmotor_a | vmotor_b | vmotor_bias | leg
1791391089.7893 | tape_pre | 0 | 0 | 0 | 300614 | 280 | 2650 | 0 | 0 | 4170 | 0 | 138141 | 1985 | 1180 | 1180 | 1772 | 0 | 0 | 0 | 0 | 0 | 1181 | 771 | 772 | 770 | pre
1791391089.7915 | tape_on | 0 | 0 | 0 | -2442240 | 280 | 2650 | 0 | 0 | 4170 | 0 | 138173 | 1987 | 1191 | 1180 | 1770 | 0 | 0 | 0 | 0 | 0 | 1190 | 773 | 773 | 770 | on
1791391089.8137 | tape_on | 0 | 0 | 1 | 135331840 | 280 | 2650 | 8702 | 2065 | 4170 | 235 | 138615 | 1986 | 1415 | 1180 | 1748 | 279 | 1726 | 8762 | 27 | 9 | 1189 | 2365 | 633 | 770 | on
1791391089.8376 | tape_on | 0 | 0 | 1 | 310181888 | 280 | 2650 | 12739 | 4733 | 4170 | 261 | 139090 | 1987 | 1441 | 1180 | 1747 | 260 | 1730 | 12950 | 57 | 9 | 1191 | 2373 | 643 | 770 | on
1791391089.8632 | tape_on | 0 | 0 | 1 | 387710976 | 280 | 3000 | 13107 | 5916 | 4226 | 182 | 139602 | 1986 | 1362 | 1180 | 1751 | 168 | 1743 | 13107 | 89 | 8 | 1190 | 2380 | 639 | 770 | on
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

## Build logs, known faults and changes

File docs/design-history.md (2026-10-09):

# Design history — what I tried, and what it taught

The transport did not arrive at its shape by foresight. It got there by
building the obvious thing, measuring it, and deleting it — repeatedly. This
file is the itemized record of the abandoned paths and the lessons they
distilled, so a reader gets the war stories without the git archaeology. The
arc in one line: the firmware first spoke Dynamixel Protocol 2.0, made it
work, and then replaced the protocol itself on the strength of one fact: I
control both ends of the wire.

Companion pillars: `osc-native-protocol.md` (the wire),
`osc-servo-transport.md` (the receiver), `driver-pattern.md` (the layering).

## The protocol pivot

### Dynamixel Protocol 2.0 as the wire protocol

I implemented and tuned a complete DXL 2.0 stack — parser, hardware reply
timing, Fast chain CRC, clock calibration — and it worked: 62.8 µs measured
ping turnaround at the end of its tuning arc. I replaced it anyway. Every
hard problem in that stack traced to one wire-format fact: DXL has no
out-of-band delimiter, so it needs `FF FF FD` header hunting, byte stuffing
to keep the header out of payloads, and a stuffed length that isn't known
until the whole payload is walked — which forbids streaming TX outright. Add
10–12 bytes of overhead per frame, the RDT reply-grid tuning surface, and
byte-granular indirect registers that force replies through a per-byte
pointer chase (defeating both the hardware CRC engine and copy-once TX), and
the stack's complexity was the protocol's, not ours. A UART break is an
out-of-band delimiter: framing became 5 bytes + a break, the receiver became
a two-state framer, and the stuffing, hunting, and reply-grid subsystems
stopped existing. Lesson: when you control both ends of the wire, fix the
wire — a delimiter the data cannot forge deletes entire subsystems.

## Receive machinery built, measured, deleted

### Per-byte streaming RX parser

The first receiver walked the wire byte by byte: an event-per-protocol-field
iterator pumped into a stateful dispatcher that tracked each in-flight
instruction across the event sequence. The per-byte pipeline measured ~55%
of the CPU during sustained 3 Mbaud reception — spent producing a
granularity no consumer used. Reply timing needs one number per frame, chain
sequencing needs frame boundaries, drift estimation needs a rate over a
burst. Deleted for whole-frame classification: probe the header, copy once,
decode once, one verdict per frame. Lesson: precision nobody downstream
spends is pure cost — find what consumers actually need before building the
producer.

### Hardware input-capture RX timing

Early bringup timestamped every falling edge on the RX pin through timer
input capture: a DMA-drained edge-stamp ring and a classifier walker turned
edge times into per-byte wire ticks. It worked, and it was the single
largest CPU consumer in the transport. All ~3000 lines were deleted and RX
timing became fully software once measurement showed every timing consumer
met its tolerance from plain clock reads. Lesson: RX jitter does not
propagate to the wire — only TX jitter does. Spend hardware where error
reaches the wire; software is fine everywhere else.

### The USART's LIN break detector as the wake

The length-qualified wake first lived on the USART's LIN break detector
(LBD, enabled without the LIN engine), measured clean on the rev B board's
buffered wire, where RX had its own pin: law breaks 2000/2000 with its
flag-selective write-0 clear running mid-traffic, and zero entries across
framing-error injection and high-baud garble. Rev 2A runs the bus on one
pin under HDSEL, and there the V006 never sets LBD, in any configuration
tried; the same die sets it with HDSEL off. The servo received every frame
into the ring and never woke to resolve one. The wake moved to TIM2 on the
bus pin: an edge-reset counter whose overflow at 9.25 bit-times latches
the pin level by DMA. That detector fires a break-length in, not at the
span's end, so it can beat the break's own `0x00` into the ring; the
ring-dependent service moved behind a one-byte-time re-inspection, and the
reply's own break, which the pin sees though the receiver does not, is
sent with the detector muted. Lesson: a peripheral feature measured in one
wiring is not measured in another - bring up the production wiring before
building on it.

### The edge-reset TIM2 detector

The first TIM2 wake zeroed its counter on every wire edge (slave reset
mode on TI1F_ED) and overflowed after 9.25 bit-times of either level, so
it timed every quiet span, high or low. A DMA latch of the pin at the
overflow told a break from idle, the service parked the update, and the
next edge's trigger interrupt re-armed it. Each ping cost about five
TIM2 entries (a break, an idle, three re-arms), and the idle entry landed
inside the turnaround window, where it could hold off the reply-start
deadline at the same PFIC level; turnaround and kernel ticks lost per ping
both measured worse than under LBD. Gating the counter on the low level
and zeroing it by DMA on each rising edge put the whole qualification in
hardware: an overflow can only be a break, and a ping costs one entry.
Lesson: qualify in the peripheral, so the interrupt carries only the
event.

## Transmit timing the break made obsolete

### Hardware-timed TX kickoff + RDT

To hit DXL's reply grid, a timer-compare match fired a DMA write that
enabled the TX stream — zero CPU in the deadline path — backed by
per-fire-path lead-calibration constants and a wrap-guard arming dance. All
of it existed because DXL schedules replies on a clock grid. Break framing
made reply timing event-driven: send the break when ready, and the break
itself tells every listener a frame is starting. The kickoff hardware, the
RDT register, and the whole lead-tuning surface were deleted. Lesson: the
best exit from a precision-timing problem is a protocol that doesn't pose
it.

## Clock discipline: the long road to CAL

### Fire-intercept calibration (DXL era)

The chip has no crystal, and its RC oscillator drifts enough to break
chain timing at 3 Mbaud. The first calibration was a three-knob
decomposition — HSITRIM for the drift slope, a per-family structural-latency
intercept, a per-chip sub-trim residual — derived host-side from a
crystal-clocked timer stamping a stimulus reply. It was correct and it was
heavy: biased rounding rules, Q8.8 unit plumbing, per-family
characterization sweeps. The break-framed protocol deleted its main
consumer (the reply grid), and the replacement ruler is one broadcast
instruction: the host emits breaks spaced exactly T µs apart and the servo
stamps its own wake entries — same ISR path both ends of every gap, so
entry latency cancels in the difference. The lesson survives unchanged: a
chip cannot time itself. SysTick, the UART, and ISR latency all derive from
the oscillator under test; every self-measurement is structurally biased.
You need a reference on a clock domain that isn't the one being measured.

### Passive drift estimator

Between calibrations, thermal drift still needs tracking. The first tracker
eavesdropped: it sampled the host's byte cadence at mid-frame resolver
wakes. It starved — the frames long enough to qualify barely exist in real
traffic — and its software-phased stamps needed a dither/floor/gate pipeline
just to launder their quantization. Replaced by the differential chain-pair
tracker: break-wake stamps bracketing one CRC-verified silent instruction,
with a post-trim baseline subtraction that kills every constant (host
queuing seam, detector latch offset, ISR flavor residue) so only drift
survives. Lesson: when only the host has the truth — it owns the crystal —
ask the host to cooperate instead of eavesdropping on it.

The chain-pair tracker was deleted in turn. It needed each break's time
and its position in the ring, and the V006 delivers those on two separate
paths: the ISR entry lags the detector by up to two frames under load and
merges breaks, so stamps moved to a DMA latch (DMA1 CH2 copying TIM3 on
the detector's update), which then had to be paired with ring positions
by order after the fact - floors, take-after-reply, clears on CAL marks,
rate changes and rescues, a 16-bit unwrap. Every pairing heuristic had a
misfire case, and the transport bugs of a whole week sat in that one
layer. The trim now moves only on a CAL; the host re-sends CAL
periodically to follow thermal drift. Lesson: if the hardware cannot tag
an event with both its time and its place, do not build a mechanism that
needs both - ask the reference to come to you.

## Position and time from wake evidence: three dead ends

### Capture FIFO / deferred dispatch

Zero-gap bursts lost frames, and the diagnosis pointed at ISR latency: a
long dispatch body delays break service, breaks coalesce, the late handler
misreads the ring. So I queued — a capture FIFO that snapshotted the ring
cursor at each event for later processing. Reverted: probes proved the
snapshots were already stale *at capture time*; fixing latency attacked the
wrong term. The design rule since: position is derived from the stream,
never sampled at ISR entry. Latency merely amplifies staleness — remove the
staleness and latency stops meaning loss.

### Per-event timestamps → ring-cadence time

The break wake once carried one timestamp — its own delivery tick — as the
frame's clock anchor. Everything timed from it inherited ISR delivery lag
wholesale: a wake serviced 60 µs late made the reply 60 µs late. Replaced by
projecting `now + missing byte-times` from live ring state at every resolve.
`now` and the ring cursor advance together, so delivery lag cancels out of
the projection; the residual error is bounded under a byte-time and always
on the late side, never early. The wake carries nothing now — not position,
not time. It is only a wake.

### Error-flag wake + fault fence + storm mute

The receive wake originally lived on the UART's framing-error flag, and I
twice shipped machinery that extracted more than a wake from it: a
positional fault fence (record where the error was seen, kill frames behind
it) and a service-time storm mute (throttle a flag that re-fires). Both
passed every quiet-wire test. Both killed live frames under fleet load —
service-time cursors lie under ISR lag and latch re-fires — and the mute's
restore chain wedged servos deaf to rescue. The resolution inverted the
premise: wake on the length-qualified break detector, and leave the error
flags with no interrupt enabled at all. Errors never interrupt; their
consequences surface where data-driven handling already looks (a corrupt
byte fails its frame's CRC). Lesson: latched, positionless, coalescing
signals cannot be event sources — don't build event machinery on one.

## Dispatch placement

### Class-routing carve-out (heavy dispatch at low priority)

To keep long dispatch bodies from preempting the motor kernel, heavy
instruction classes were routed across a priority boundary: staged through a
one-slot handoff to a low-priority consumer. It bought kernel isolation and
cost ack-bearing writes a cross-priority hop and an adoption round-trip —
and the handoff machinery (slot FSM, two wake lanes, adoption guard) became
the single largest complexity center in the transport. Deleted, ~800 lines,
once silicon measurement settled the question the structure was built to
avoid asking: kernel tick coalescing under realistic bus duty is negligible.
Lesson: measure the cost before building structure to avoid it.

## Smaller calls that shaped the design

### Torque-gated EEPROM writes

DXL gates every config-region write behind torque-off — a category error
that conflates the storage medium with the data's mutability. The actual
mid-motion hazard is the flash program operation, which stalls instruction
fetch for milliseconds under a live control loop. So only SAVE is gated;
config writes always land in the RAM table, volatile until saved. Flash wear
drops to program-per-session and the write stall happens exactly once, at a
moment the user chose. Lesson: gate the hazard, not the category.

### Async/await on the servo side

Rust async was considered for the bus driver and rejected. Executor
wake→poll overhead per frame is real money against a ~41 µs turnaround
budget on a 48 MHz RV32EC, and async costs control of code placement — hot
paths must land in RAM sections deliberately, which the executor's generated
state machines defeat. The driver is instead a composed set of explicitly
scheduled state machines driven by two interrupt vectors: the scheduling is
the design, not plumbing to be abstracted away.

### Framing alternatives that lost to the break

Recorded so they are not re-derived. Closing double-break (a break at both
ends of every frame): deletes every receiver clock, but costs wire time per
frame and gives up dispatching under the instruction's own wire time.
Covered-position break (delimiter at the payload/CRC boundary): a
wire-native dispatch trigger, but it resurrects the commit/revert machinery
it was meant to delete. Sync bytes, header checksums, parity: each adds wire
cost to buy detection the break + CRC + host-retry contract already
provides, and none deletes receiver machinery. Break framing is the strong
form of sync — DXL's `FF FF FD` + stuffing is the workaround for not having
an out-of-band delimiter at all.

## Recurring lessons

- **Measure before structuring.** Twice I built structure to avoid a cost
  nobody had measured; both times the measurement, once taken, deleted the
  structure.
- **Delete machinery rather than tuning it.** Every major win here was a
  subtraction; a fix that adds a knob is usually aimed at the wrong term.
- **Data over wake evidence.** Positions come from the stream, times from
  cadence projections; nothing derived at ISR entry survives load.
- **A clock needs an external reference.** Every self-measurement path
  shares the oscillator under test.
- **Gate hazards, not categories.** Find the actual dangerous operation and
  gate exactly that.
- **Precision nobody spends is pure cost.** Identify what consumers need
  before building the producer.
- **When you control both ends, fix the wire.** Complexity moved into the
  wire format's construction is deleted from every implementation, forever.

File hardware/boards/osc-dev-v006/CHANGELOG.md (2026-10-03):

# OSC Dev CH32 - Changelog

Hardware revisions of the OSC Dev CH32 (`osc-dev-v006`) board. Newest first.

To get files at a specific revision, check out the corresponding tag (e.g. `git checkout osc-dev-v006-rev-a`) or browse the merge commit linked below.

---

## Rev 2A - 2026-08-02

**Status:** Built and brought up. Board #1 runs an MG90 on 2S through calibration, identification and closed-loop verify; the encoder inputs, Qwiic and `POS2` are not exercised yet. Value changes that need no routing change stay Rev. 2A. Board silk reads `Dev V006 Rev. 2A`.

### Removed

- 74LVC2G241 UART bus buffer and its RX jumper. `DATA` wires directly to the MCU through a 33 Ohm series resistor (`Rx1`), and direction turnaround and RX timing are fully in firmware.
- USB-C and screw-terminal power inputs. Battery (JST-PH) and LinkE 5 V remain, still SS54-OR'd.
- PWM servo header.
- Edge test-point hook rails. Nine 1.0 mm probe pads, most of them in two rows next to the sense network, replace them: ground, op-amp output, both PWM inputs, the three divider taps and the two position channels.
- Second UART. Telemetry rides the `DATA` wire as bounded CRC'd bursts, so there is no telemetry pin, no LinkE TX / RX wiring and no TEL lamp.
- Ferrite bead on the driver logic rail. The DRV8212P VCC (`+3V3_DRV`) now hangs off the MCU's `+3V3` through Rh2, a fitted 0R that keeps the bead as a swap option.
- OPA to CMP2 hardware stall detection. V006 has no comparator units, so protection is layered instead: driver OCP / TSD, a kernel I2t limit that drops `DRV_EN` and latches a user-clearable stall fault, IWDG, and the `DRV_EN` pulldown that kills the bridge on any reset.

### Added

- **Qwiic connector** (I2C, 4K7 pull-ups, 100 Ohm series) for an encoder module, magnetic or quadrature breakout.
- **`VB` bias node** for the motor terminal dividers, so both terminals stay readable while the bridge coasts.
- **Motor encoder flex landing.** J11 is a row of six bare 1.0 mm pads (`GND` / `+3V3` / `ENCA` / `ENCB` / `VNTC_EXT` / `GND`) for the tier-3 IR encoder flex, soldered tin-and-iron. It parallels the J6 encoder pins and adds the on-can thermistor into the JP2 external leg.
- **Second analog position channel.** J5 is 1x04 (`+3V3` / `GND` / `POS1` / `POS2`) for a dual-output transducer; `POS2` shares ADC `A0` (`PA2`) with the NTC through JP2, behind the same 4K7 / 100nF filter as `POS1`. Jump JP2 for the NTC, leave it open for the second channel.
- **DNP experiment footprints** around the current sense block: comp-cap stack (`Cc3`/`Cc4`), kelvin filter (`Ck1`), output cap (`Co1`), VREF shift (`Rd3`), bus pull-up (`Rx2`), plus fitted 0R kelvin series swap points (`Rk1`/`Rk2`).
- ESD clamp (PESD5V0L1BA) on the bus `DATA` line, ahead of the series resistor.
- **Function-family reference designators.** Passives carry a letter for the net they serve rather than a flat number, so `Rv1` and `Cv1` belong to the same divider. See the README.
- QR code on the back silk linking to the board README.

### Changed

- **Current sense reworked for accuracy.** 60 mOhm kelvin-connected shunt (`Rs1`) with net-tie midpoint taps, the only tie between `PGND` and `GND`, and the on-chip op-amp running in bare mode behind an external four-resistor difference network. G = 14.88 (6K4/430) for 893 mV/A, biased at VREF = 0.52 V so both current directions are visible. Precision money goes to the shunt and the Rf / Rg quad; everything downstream is offset that boot calibration eats.
- **Motor terminal sense is now differential and coast-readable.** 6K4/1K6 dividers on both terminals, ratio 0.20, with their bottoms and filter caps returning to the 0.623 V `VB` node instead of GND. Neither the coast diode phase nor a 2S rail clips, so `vA - vB` is real back-EMF and the rail comes back as `5 x tap - 4 x VB`. `VB` is read at boot with the driver parked: with the bridge Hi-Z both taps sit at `VB` itself.
- **`VSNS` moved to its own pin.** `VSYS` is sensed directly through a 6K4/1K6 divider with a 100 pF cap into `A2` (`PC4`), instead of being inferred from a driven terminal. Ratio 0.20 and the same reels as the terminal dividers, so the two chains track and rail minus terminal resolves the bridge drop.
- Bridge decoupling returns to `GND`, not `PGND`, so the chopped motor loop has to cross the shunt instead of bypassing it.
- WCH-LinkE header is 1x03 (5 V / GND / SWDIO) instead of 2x03.
- Encoder input (J6) is ADC-only by design. `PD2`/`PD3` don't carry TIM2 CH1/CH2, so digital encoders go on Qwiic instead. J6 targets an ADC-sampled IR quadrature encoder.
- 4 layers -> 6 layers, 50 x 40 mm, JLCPCB JLC06161H-3313 stackup, ENIG, via-in-pad. The motor path is a zero-via top-layer corridor to a through-hole motor connector.
- `SB1` bootstrap solder bridge became `JP1`. Same one-time `RST_MODE=11` first-boot procedure, and the op-amp `+` input now shares the pin.
- All connectors renumbered. The LED set is now VSYS / 3V3 / DAT / STA.

---

## Rev B - 2026-04-28

**Status:** Validated. Merged in [PR #10](https://github.com/OpenServoCore/open-servo-core/pull/10). In-rev patch: `SB1` bootstrap solder bridge added for the shared `nRST` / `OPN2` pin. Version label unchanged - published files include the patch.

### Fixed (from Rev A)

- VDD / VCC rail label swap.
- Top-row test-point labels.
- Encoder connector labels.
- Battery connector polarity (JST PH 2P).
- TX_EN / UART buffer conflict - added a jumper for RX <-> buffer so UART works without firmware workaround.

### Added

- **Hardware-based stall detection / overcurrent protection** - internal OPA -> CMP2 path. No extra parts.
- **External NTC connector** with onboard / external selection jumper.
- **Traditional PWM servo header** (driven from IN1) for servo identification and measurement.
- **VSNS net** - VSYS measured directly instead of derived from VSNA / VSNB.
- **WCH-LinkE connector**: 5 V pin (replacing the unused RST pin) gated by an SS54 for safety.
- **`SB1` bootstrap solder bridge** (in-rev patch) - `nRST` and `OPN2` share a pin; the bridge breaks the path during `nRST -> GPIO` option-byte programming, then closes for normal current-sense operation. See [Fabrication](README.md#fabrication).

### Changed

- **MCU pin remap:**
  - `ENCA` / `ENCB` selectable between TIM2 and ADC.
  - `ISNS+` / `ISNS-` moved to OPP0 / OPN2 to feed the differential OPA.
  - `STAT` LED moved to a TIM1 channel.
  - `nRST` removed (USER option byte programmed at provisioning; pin freed for OPA / GPIO use).
- Reset button and its RC debounce network removed (nRST gone).
- Board renamed `servo-dev-board-ch32v006` -> `osc-dev-v006` to match the product naming convention.

---

## Rev A - 2026-03-01

**Status:** Built, validated. **Deprecated - do not fab.** Superseded by Rev B. Merged in [PR #5](https://github.com/OpenServoCore/open-servo-core/pull/5).

Initial CH32V006-based dev board. PCBWay-sponsored fab. Brought up and validated end-to-end before known issues and pin-mapping limits drove the Rev B respin.

### Known issues (fixed in Rev B)

- VDD / VCC rail label swap.
- TX_EN pull-up conflict on the half-duplex UART buffer.
- Top-row test-point labels.
- Encoder connector labels.
- Battery connector (JST PH 2P) polarity reversed.

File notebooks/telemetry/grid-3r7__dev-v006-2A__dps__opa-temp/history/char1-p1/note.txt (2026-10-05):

Stock board #1 characterisation: board in the dryer (JP2 IN, onboard TH1), 3.7 ohm grid on J4 outside at room, pack + adapters outside. Plateaus room / dryer 40 / dryer 70. Static bursts at 10/15/25/40% (limit 1000 counts RAM). regs.csv = 30 torque-off snapshots per plateau.

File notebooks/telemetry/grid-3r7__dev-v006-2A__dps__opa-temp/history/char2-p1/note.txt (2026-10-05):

After: board #1 with VREF raised (Rd2 1K6 + Rd3 1K6, 1.10 V; rest zero 1101 counts), Rn1 10K thin film, firmware b1e1f6d8 (zero tracking #257, burst interleave #258), oc_trip 2439 saved. Board in the dryer, grid outside on J4, JP2 IN. Plateaus room / dryer 50 / dryer 70. Bursts alternate driven (even) and diff (odd), static load, rungs 10/15/25/38%, limit 1000 counts RAM.

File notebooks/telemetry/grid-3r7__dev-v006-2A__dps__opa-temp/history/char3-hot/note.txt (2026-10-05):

HS OFF experiment (OPA_HS1=0, local build on b1e1f6d8, not committed). Same board/rework as char2. Hot point first (dryer 70, board ~59 C), then room after cool-down.

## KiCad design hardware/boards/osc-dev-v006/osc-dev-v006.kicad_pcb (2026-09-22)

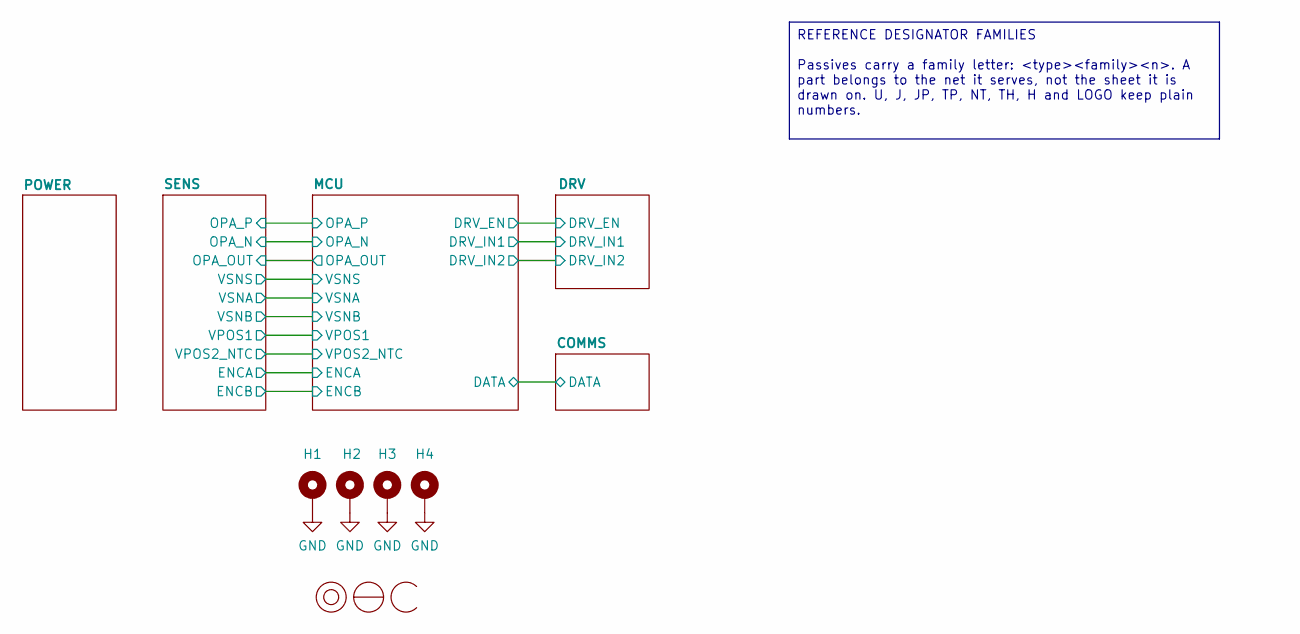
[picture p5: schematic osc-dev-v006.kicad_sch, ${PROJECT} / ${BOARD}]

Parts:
H1, H2, H3, H4: MountingHole_Pad_MP; MountingHole_2.2mm_M2_ISO7380_Pad
LOGO1: osc-logo; osc

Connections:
GND: H1.1 (1_1), H2.1 (1_1), H3.1 (1_1), H4.1 (1_1); also elsewhere on the board

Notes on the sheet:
REFERENCE DESIGNATOR FAMILIES Passives carry a family letter: <type><family><n>. A part belongs to the net it serves, not the sheet it is drawn on. U, J, JP, TP, NT, TH, H and LOGO keep plain numbers.

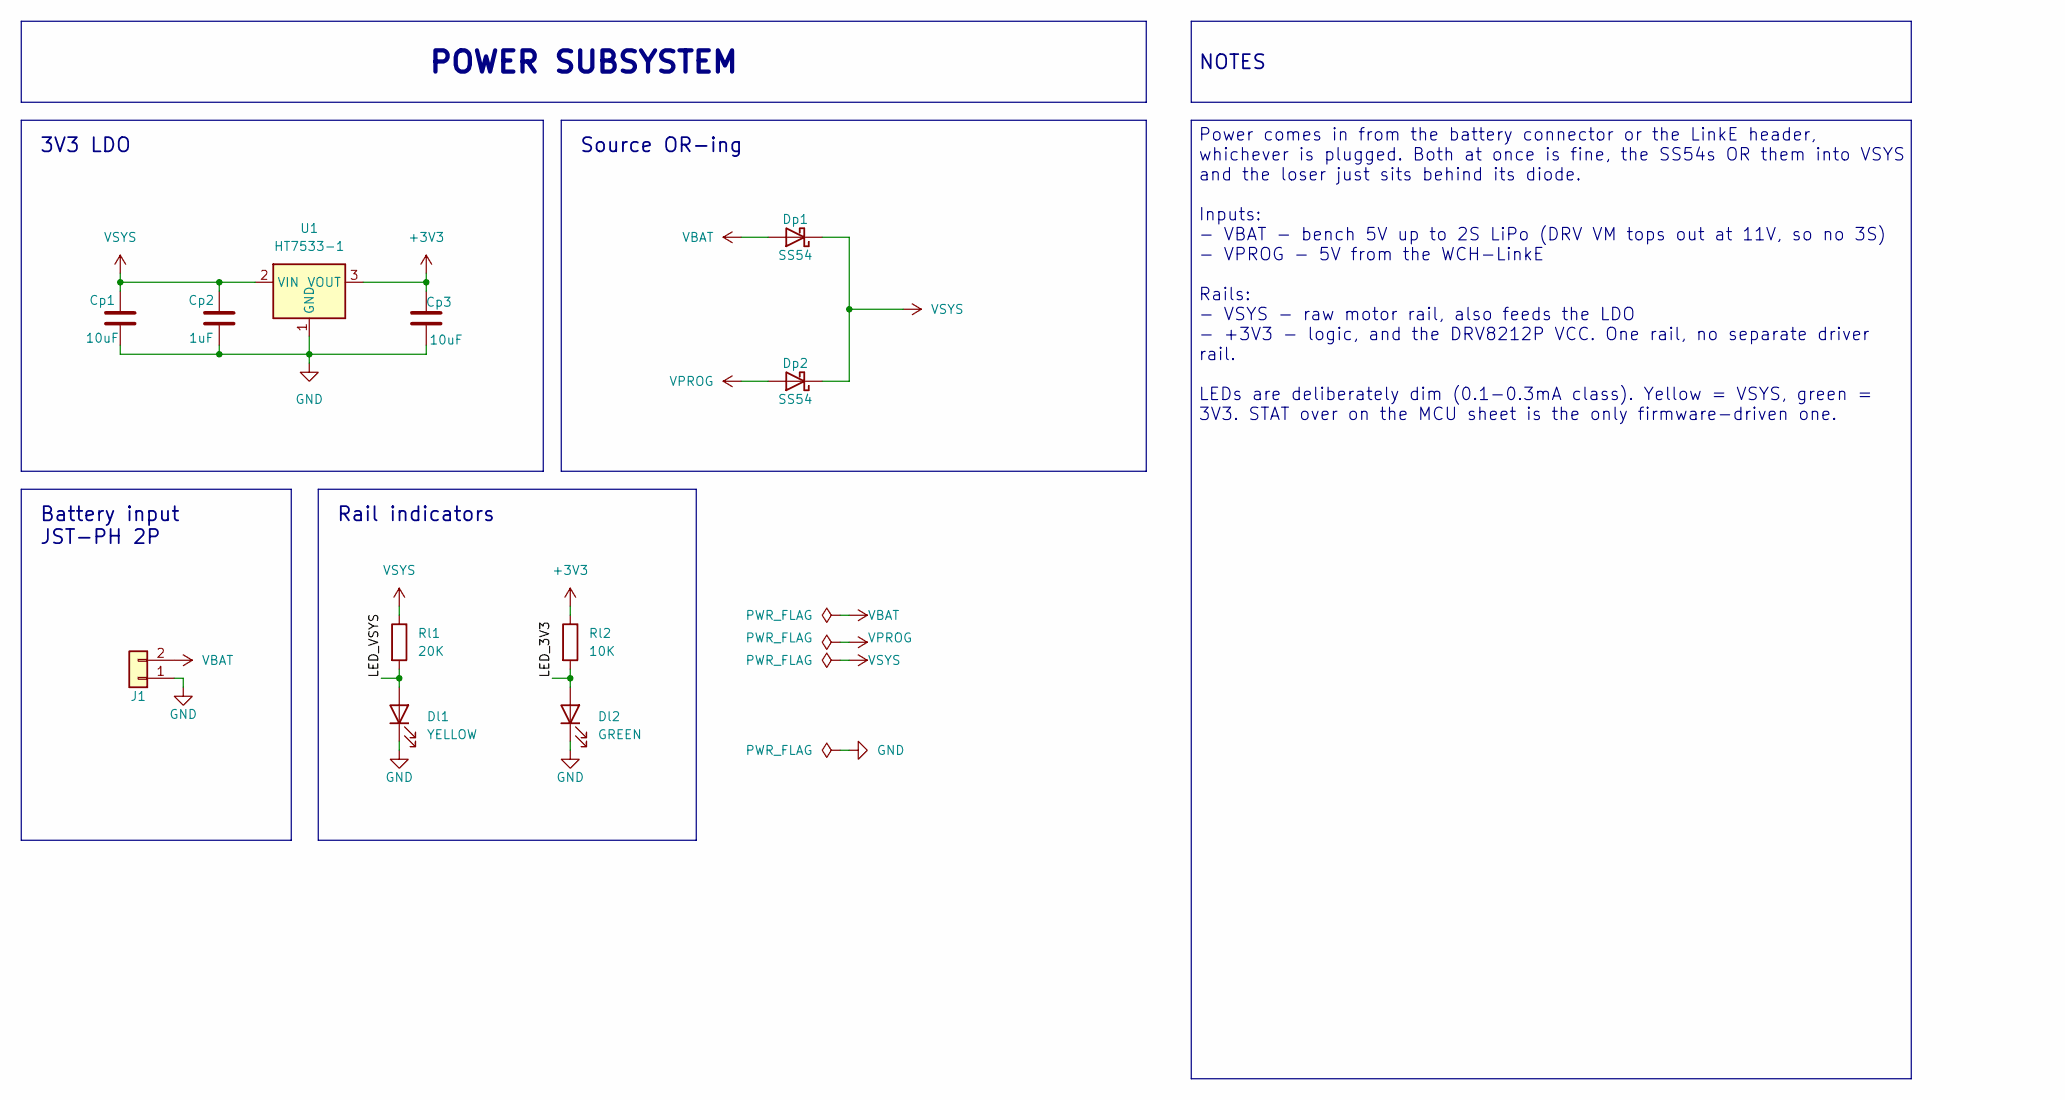
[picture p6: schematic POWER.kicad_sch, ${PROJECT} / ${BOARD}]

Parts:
Cp1, Cp3: 10uF; C_0805_2012Metric_Pad1.18x1.45mm_HandSolder; LCSC C15850
Cp2: 1uF; C_0603_1608Metric_Pad1.08x0.95mm_HandSolder; LCSC C559769
Dl1: YELLOW; LED_0603_1608Metric_Pad1.05x0.95mm_HandSolder; LCSC C497929
Dl2: GREEN; LED_0603_1608Metric_Pad1.05x0.95mm_HandSolder; LCSC C497927
Dp1, Dp2: SS54; D_SMA_Handsoldering; LCSC C22452
J1: JST-PH-H; CONN-TH_S2B-PH-K-S-LF-SN; LCSC C173752
Rl1: 20K; R_0603_1608Metric_Pad0.98x0.95mm_HandSolder; LCSC C2907011
Rl2: 10K; R_0603_1608Metric_Pad0.98x0.95mm_HandSolder; LCSC C2906982
U1: HT7533-1; SOT-89-3_Handsoldering; LCSC C14289

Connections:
+3V3: Cp3.1, Rl2.1, U1.3 (VOUT); also elsewhere on the board
/POWER/LED_3V3: Dl2.2 (A), Rl2.2
/POWER/LED_VSYS: Dl1.2 (A), Rl1.2
GND: Cp1.2, Cp2.2, Cp3.2, Dl1.1 (K), Dl2.1 (K), J1.1, U1.1 (GND); also elsewhere on the board
VBAT: Dp1.2 (A), J1.2
VPROG: Dp2.2 (A); also elsewhere on the board
VSYS: Cp1.1, Cp2.1, Dp1.1 (K), Dp2.1 (K), Rl1.1, U1.2 (VIN); also elsewhere on the board

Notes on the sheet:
Battery input JST-PH 2P
3V3 LDO
Rail indicators
Source OR-ing
NOTES
Power comes in from the battery connector or the LinkE header, whichever is plugged. Both at once is fine, the SS54s OR them into VSYS and the loser just sits behind its diode. Inputs: - VBAT - bench 5V up to 2S LiPo (DRV VM tops out at 11V, so no 3S) - VPROG - 5V from the WCH-LinkE Rails: - VSYS -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
POWER SUBSYSTEM

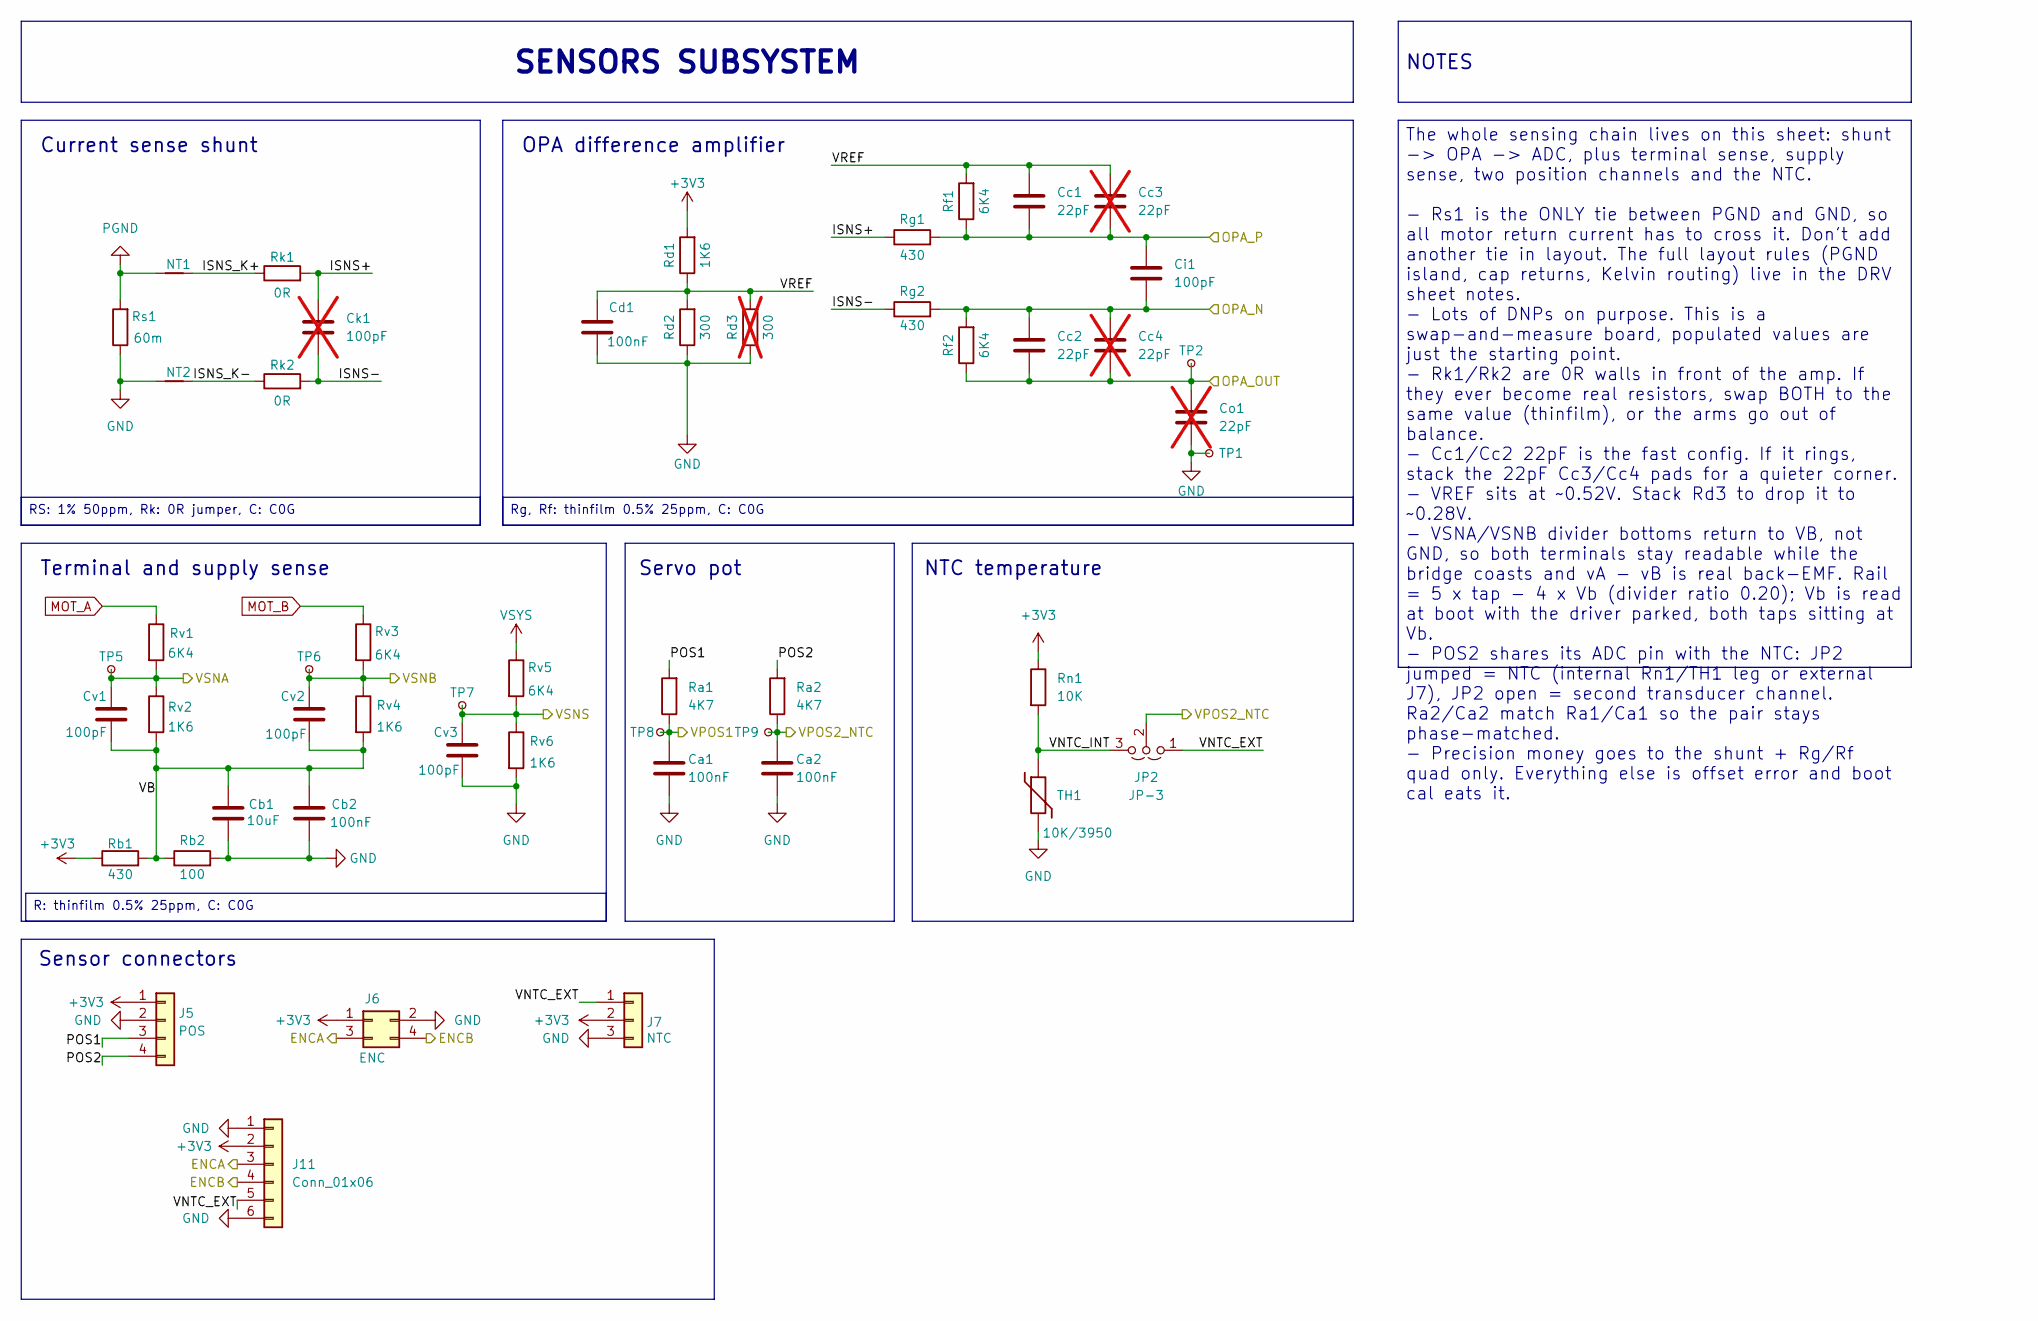
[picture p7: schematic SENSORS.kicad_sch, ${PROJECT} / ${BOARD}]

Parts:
Ca1, Ca2: 100nF; C_0603_1608Metric_Pad1.08x0.95mm_HandSolder; LCSC C14663
Cb1: 10uF; C_0805_2012Metric_Pad1.18x1.45mm_HandSolder; LCSC C15850
Cb2: 100nF; C_0603_1608Metric_Pad1.08x0.95mm_HandSolder; LCSC C14663
Cc1, Cc2: 22pF; C_0603_1608Metric_Pad1.08x0.95mm_HandSolder; LCSC C105620
Cc3, Cc4: 22pF; C_0603_1608Metric_Pad1.08x0.95mm_HandSolder; LCSC C105620; not fitted
Cd1: 100nF; C_0603_1608Metric_Pad1.08x0.95mm_HandSolder; LCSC C14663
Ci1: 100pF; C_0603_1608Metric_Pad1.08x0.95mm_HandSolder; LCSC C14665
Ck1: 100pF; C_0603_1608Metric_Pad1.08x0.95mm_HandSolder; LCSC C14665; not fitted
Co1: 22pF; C_0603_1608Metric_Pad1.08x0.95mm_HandSolder; LCSC C14665; not fitted
Cv1, Cv2, Cv3: 100pF; C_0603_1608Metric_Pad1.08x0.95mm_HandSolder; LCSC C14665
J5: POS; PinHeader_1x04_P2.54mm_Vertical
J6: ENC; PinHeader_2x02_P2.54mm_Vertical; LCSC C66690
J7: NTC; PinHeader_1x03_P2.54mm_Vertical; LCSC C49257
J11: Conn_01x06; Flex_Landing_1x06_P1.0mm
JP2: JP-3; PinHeader_1x03_P2.54mm_Vertical; LCSC C41425293
NT1, NT2: NetTie_2; NetTie-2_SMD_0.2mm
Ra1, Ra2: 4K7; R_0603_1608Metric_Pad0.98x0.95mm_HandSolder; LCSC C2907034
Rb1: 430; R_0603_1608Metric_Pad0.98x0.95mm_HandSolder; LCSC C374586
Rb2: 100; R_0603_1608Metric_Pad0.98x0.95mm_HandSolder; LCSC C125923
Rd1: 1K6; R_0603_1608Metric_Pad0.98x0.95mm_HandSolder; LCSC C374557
Rd2: 300; R_0603_1608Metric_Pad0.98x0.95mm_HandSolder; LCSC C374566
Rd3: 300; R_0603_1608Metric_Pad0.98x0.95mm_HandSolder; LCSC C374566; not fitted
Rf1, Rf2: 6K4; R_0603_1608Metric_Pad0.98x0.95mm_HandSolder; LCSC C374580
Rg1, Rg2: 430; R_0603_1608Metric_Pad0.98x0.95mm_HandSolder; LCSC C374586
Rk1, Rk2: 0R; R_0603_1608Metric_Pad0.98x0.95mm_HandSolder; LCSC C95177
Rn1: 10K; R_0603_1608Metric_Pad0.98x0.95mm_HandSolder; LCSC C2906982
Rs1: 60m; R_1206_3216Metric_Pad1.30x1.75mm_HandSolder; LCSC C49164944
Rv1, Rv3, Rv5: 6K4; R_0603_1608Metric_Pad0.98x0.95mm_HandSolder; LCSC C374580
Rv2, Rv4, Rv6: 1K6; R_0603_1608Metric_Pad0.98x0.95mm_HandSolder; LCSC C374557
TH1: 10K/3950; R_0603_1608Metric_Pad0.98x0.95mm_HandSolder; LCSC C2889049
TP1: GND; TestPoint_Pad_D1.0mm
TP2: OPA; TestPoint_Pad_D1.0mm
TP5: VA; TestPoint_Pad_D1.0mm
TP6: VB; TestPoint_Pad_D1.0mm
TP7: VS; TestPoint_Pad_D1.0mm
TP8: VP1; TestPoint_Pad_D1.0mm
TP9: VP2; TestPoint_Pad_D1.0mm

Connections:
+3V3: J5.1, J6.1, J7.2, J11.2, Rb1.1, Rd1.2, Rn1.1; also elsewhere on the board
/MCU/ENCA: J6.3, J11.3; also elsewhere on the board
/MCU/ENCB: J6.4, J11.4; also elsewhere on the board
/MCU/OPA_N: Cc2.1, Cc4.1, Ci1.2, Rf2.2, Rg2.2; also elsewhere on the board
/MCU/OPA_OUT: Cc2.2, Cc4.2, Co1.1, Rf2.1, TP2.1 (1_1); also elsewhere on the board
/MCU/OPA_P: Cc1.2, Cc3.2, Ci1.1, Rf1.1, Rg1.2; also elsewhere on the board
/MCU/VPOS1: Ca1.1, Ra1.1, TP8.1 (1_1); also elsewhere on the board
/MCU/VPOS2_NTC: Ca2.1, JP2.2 (C), Ra2.1, TP9.1 (1_1); also elsewhere on the board
/MCU/VSNA: Cv1.1, Rv1.2, Rv2.1, TP5.1 (1_1); also elsewhere on the board
/MCU/VSNB: Cv2.1, Rv3.2, Rv4.1, TP6.1 (1_1); also elsewhere on the board
/MCU/VSNS: Cv3.1, Rv5.2, Rv6.1, TP7.1 (1_1); also elsewhere on the board
/SENS/ISNS+: Ck1.1, Rg1.1, Rk1.2
/SENS/ISNS-: Ck1.2, Rg2.1, Rk2.2
/SENS/ISNS_K+: NT1.1, Rk1.1
/SENS/ISNS_K-: NT2.1, Rk2.1
/SENS/POS1: J5.3, Ra1.2
/SENS/POS2: J5.4, Ra2.2
/SENS/VB: Cb1.1, Cb2.1, Cv1.2, Cv2.2, Rb1.2, Rb2.1, Rv2.2, Rv4.2
/SENS/VNTC_EXT: J7.1, J11.5, JP2.1 (A)
/SENS/VNTC_INT: JP2.3 (B), Rn1.2, TH1.1
/SENS/VREF: Cc1.1, Cc3.1, Cd1.1, Rd1.1, Rd2.2, Rd3.2, Rf1.2
GND: Ca1.2, Ca2.2, Cb1.2, Cb2.2, Cd1.2, Co1.2, Cv3.2, J5.2, J6.2, J7.3, J11.1, J11.6, NT2.2, Rb2.2, Rd2.1, Rd3.1, Rs1.1, Rv6.2, TH1.2, TP1.1 (1_1); also elsewhere on the board
MOT_A: Rv1.1; also elsewhere on the board
MOT_B: Rv3.1; also elsewhere on the board
PGND: NT1.2, Rs1.2; also elsewhere on the board
VSYS: Rv5.1; also elsewhere on the board

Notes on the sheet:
Terminal and supply sense
Current sense shunt
OPA difference amplifier
NTC temperature
Sensor connectors
Servo pot
Rg, Rf: thinfilm 0.5% 25ppm, C: C0G
SENSORS SUBSYSTEM
NOTES
R: thinfilm 0.5% 25ppm, C: C0G
The whole sensing chain lives on this sheet: shunt -> OPA -> ADC, plus terminal sense, supply sense, two position channels and the NTC. - Rs1 is the ONLY tie between PGND and GND, so all motor return current has to cross it. Don't add another tie in layout. The full layout rules (PGND island, cap r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
RS: 1% 50ppm, Rk: 0R jumper, C: C0G

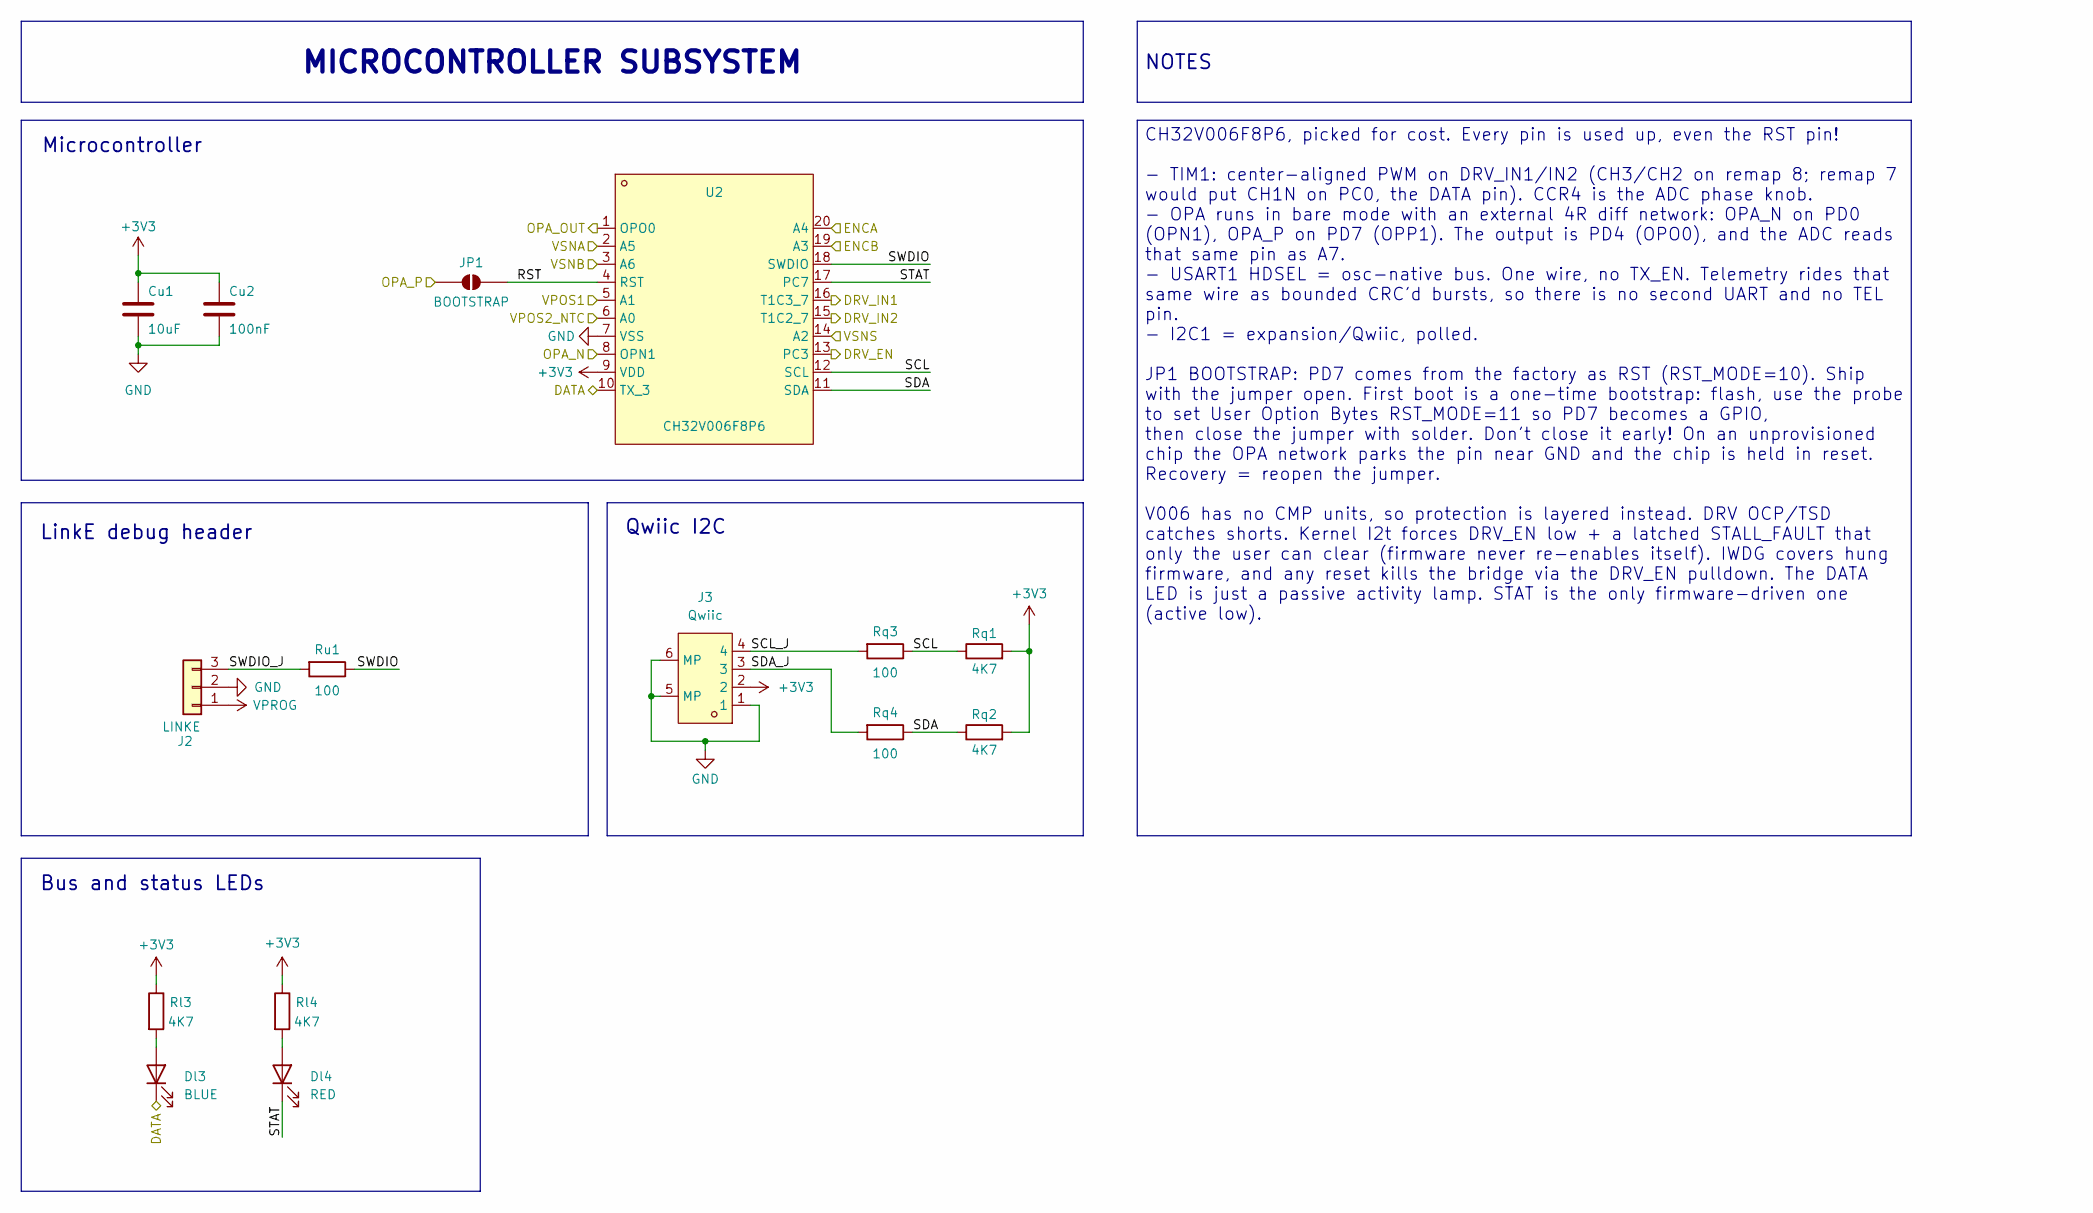
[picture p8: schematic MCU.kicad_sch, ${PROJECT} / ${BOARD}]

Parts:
Cu1: 10uF; C_0805_2012Metric_Pad1.18x1.45mm_HandSolder; LCSC C15850
Cu2: 100nF; C_0603_1608Metric_Pad1.08x0.95mm_HandSolder; LCSC C14663
Dl3: BLUE; LED_0603_1608Metric_Pad1.05x0.95mm_HandSolder; LCSC C51933294
Dl4: RED; LED_0603_1608Metric_Pad1.05x0.95mm_HandSolder; LCSC C497918
J2: LINKE; PinHeader_1x03_P2.54mm_Vertical; LCSC C49257
J3: Qwiic; CONN-SMD_SH1.0MM-4P-WT; LCSC C53055320
JP1: BOOTSTRAP; SolderJumper-2_P1.3mm_Open_TrianglePad1.0x1.5mm
Rl3, Rl4: 4K7; R_0603_1608Metric_Pad0.98x0.95mm_HandSolder; LCSC C2907034
Rq1, Rq2: 4K7; R_0603_1608Metric_Pad0.98x0.95mm_HandSolder; LCSC C2907034
Rq3, Rq4: 100; R_0603_1608Metric_Pad0.98x0.95mm_HandSolder; LCSC C125923
Ru1: 100; R_0603_1608Metric_Pad0.98x0.95mm_HandSolder; LCSC C125923
U2: CH32V006F8P6; TSSOP-20_4.4x6.5mm_P0.65mm; LCSC C52753342

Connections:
+3V3: Cu1.1, Cu2.1, J3.2, Rl3.1, Rl4.1, Rq1.2, Rq2.2, U2.9 (VDD); also elsewhere on the board
/COMMS/DATA: Dl3.1 (K), U2.10 (TX_3); also elsewhere on the board
/DRV/DRV_EN: U2.13 (PC3); also elsewhere on the board
/DRV/DRV_IN1: U2.16 (T1C3_7); also elsewhere on the board
/DRV/DRV_IN2: U2.15 (T1C2_7); also elsewhere on the board
/MCU/ENCA: U2.20 (A4); also elsewhere on the board
/MCU/ENCB: U2.19 (A3); also elsewhere on the board
/MCU/OPA_N: U2.8 (OPN1); also elsewhere on the board
/MCU/OPA_OUT: U2.1 (OPO0); also elsewhere on the board
/MCU/OPA_P: JP1.1 (A); also elsewhere on the board
/MCU/RST: JP1.2 (B), U2.4 (RST)
/MCU/SCL: Rq1.1, Rq3.1, U2.12 (SCL)
/MCU/SCL_J: J3.4, Rq3.2
/MCU/SDA: Rq2.1, Rq4.1, U2.11 (SDA)
/MCU/SDA_J: J3.3, Rq4.2
/MCU/STAT: Dl4.1 (K), U2.17 (PC7)
/MCU/SWDIO: Ru1.1, U2.18 (SWDIO)
/MCU/SWDIO_J: J2.3, Ru1.2
/MCU/VPOS1: U2.5 (A1); also elsewhere on the board
/MCU/VPOS2_NTC: U2.6 (A0); also elsewhere on the board
/MCU/VSNA: U2.2 (A5); also elsewhere on the board
/MCU/VSNB: U2.3 (A6); also elsewhere on the board
/MCU/VSNS: U2.14 (A2); also elsewhere on the board
GND: Cu1.2, Cu2.2, J2.2, J3.1, J3.5 (MP), J3.6 (MP), U2.7 (VSS); also elsewhere on the board
unnamed: Dl3.2 (A), Rl3.2
unnamed: Dl4.2 (A), Rl4.2
VPROG: J2.1; also elsewhere on the board

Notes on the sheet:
Microcontroller
Qwiic I2C
LinkE debug header
Bus and status LEDs
NOTES
CH32V006F8P6, picked for cost. Every pin is used up, even the RST pin! - TIM1: center-aligned PWM on DRV_IN1/IN2 (CH3/CH2 on remap 8; remap 7 would put CH1N on PC0, the DATA pin). CCR4 is the ADC phase knob. - OPA runs in bare mode with an external 4R diff network: OPA_N on PD0 (OPN1), OPA_P on PD7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
MICROCONTROLLER SUBSYSTEM

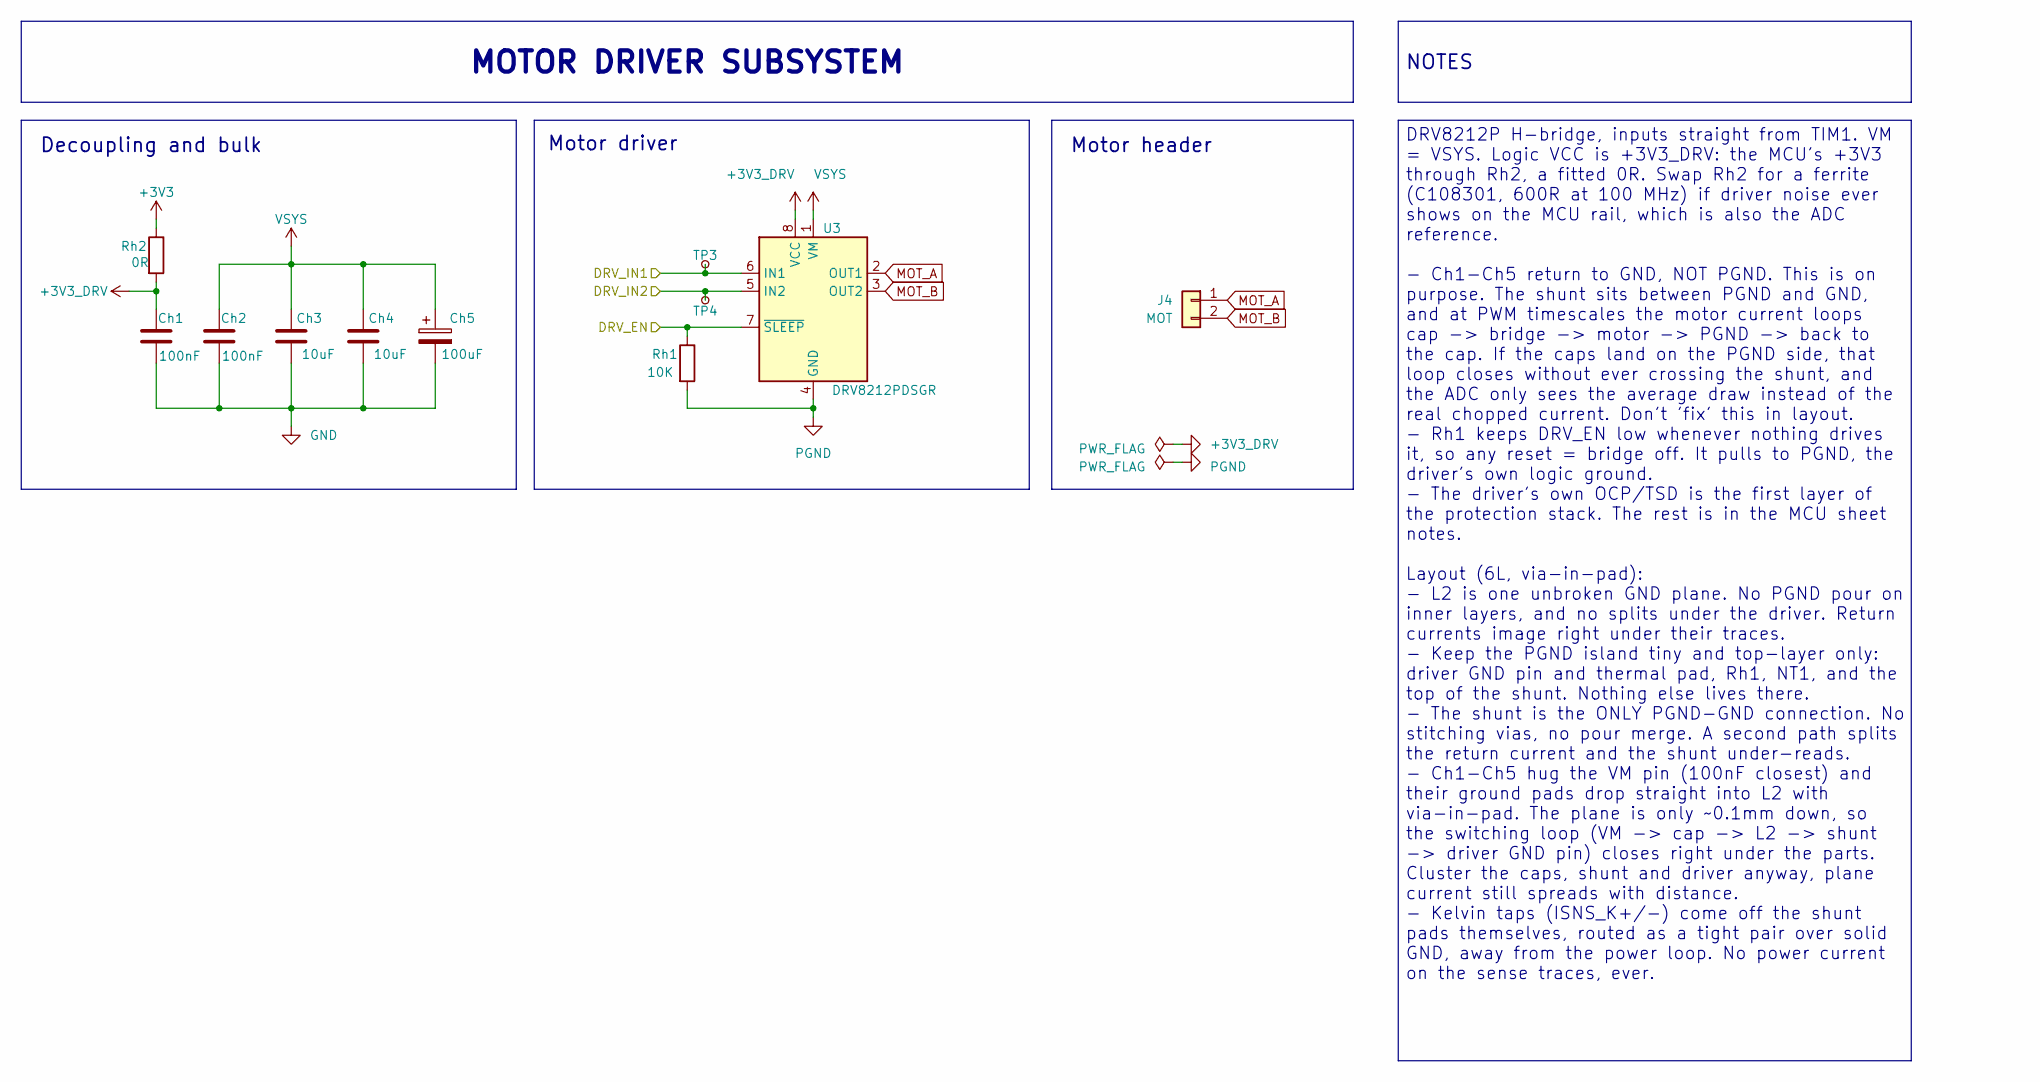
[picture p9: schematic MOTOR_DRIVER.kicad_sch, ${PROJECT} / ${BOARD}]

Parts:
Ch1, Ch2: 100nF; C_0603_1608Metric_Pad1.08x0.95mm_HandSolder; LCSC C14663
Ch3, Ch4: 10uF; C_0805_2012Metric_Pad1.18x1.45mm_HandSolder; LCSC C15850
Ch5: 100uF; CP_Elec_6.3x5.4; LCSC C22383777
J4: MOT; PinHeader_1x02_P2.54mm_Vertical; LCSC C492401
Rh1: 10K; R_0603_1608Metric_Pad0.98x0.95mm_HandSolder; LCSC C2906982
Rh2: 0R; R_0603_1608Metric_Pad0.98x0.95mm_HandSolder; LCSC C95177
TP3: IN1; TestPoint_Pad_D1.0mm
TP4: IN2; TestPoint_Pad_D1.0mm
U3: DRV8212PDSGR; Texas_DSG0008A_WSON-8-1EP_2x2mm_P0.5mm_EP0.9x1.6mm; LCSC C5208051

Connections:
+3V3: Rh2.1; also elsewhere on the board
+3V3_DRV: Ch1.1, Rh2.2, U3.8 (VCC)
/DRV/DRV_EN: Rh1.1, U3.7 (~SLEEP); also elsewhere on the board
/DRV/DRV_IN1: TP3.1 (1_1), U3.6 (IN1); also elsewhere on the board
/DRV/DRV_IN2: TP4.1 (1_1), U3.5 (IN2); also elsewhere on the board
GND: Ch1.2, Ch2.2, Ch3.2, Ch4.2, Ch5.2; also elsewhere on the board
MOT_A: J4.1, U3.2 (OUT1); also elsewhere on the board
MOT_B: J4.2, U3.3 (OUT2); also elsewhere on the board
PGND: Rh1.2, U3.4 (GND), U3.9 (GND); also elsewhere on the board
VSYS: Ch2.1, Ch3.1, Ch4.1, Ch5.1, U3.1 (VM); also elsewhere on the board

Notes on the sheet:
Motor header
Decoupling and bulk
Motor driver
MOTOR DRIVER SUBSYSTEM
NOTES
DRV8212P H-bridge, inputs straight from TIM1. VM = VSYS. Logic VCC is +3V3_DRV: the MCU's +3V3 through Rh2, a fitted 0R. Swap Rh2 for a ferrite (C108301, 600R at 100 MHz) if driver noise ever shows on the MCU rail, which is also the ADC reference. - Ch1-Ch5 return to GND, NOT PGND. This is on purpo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

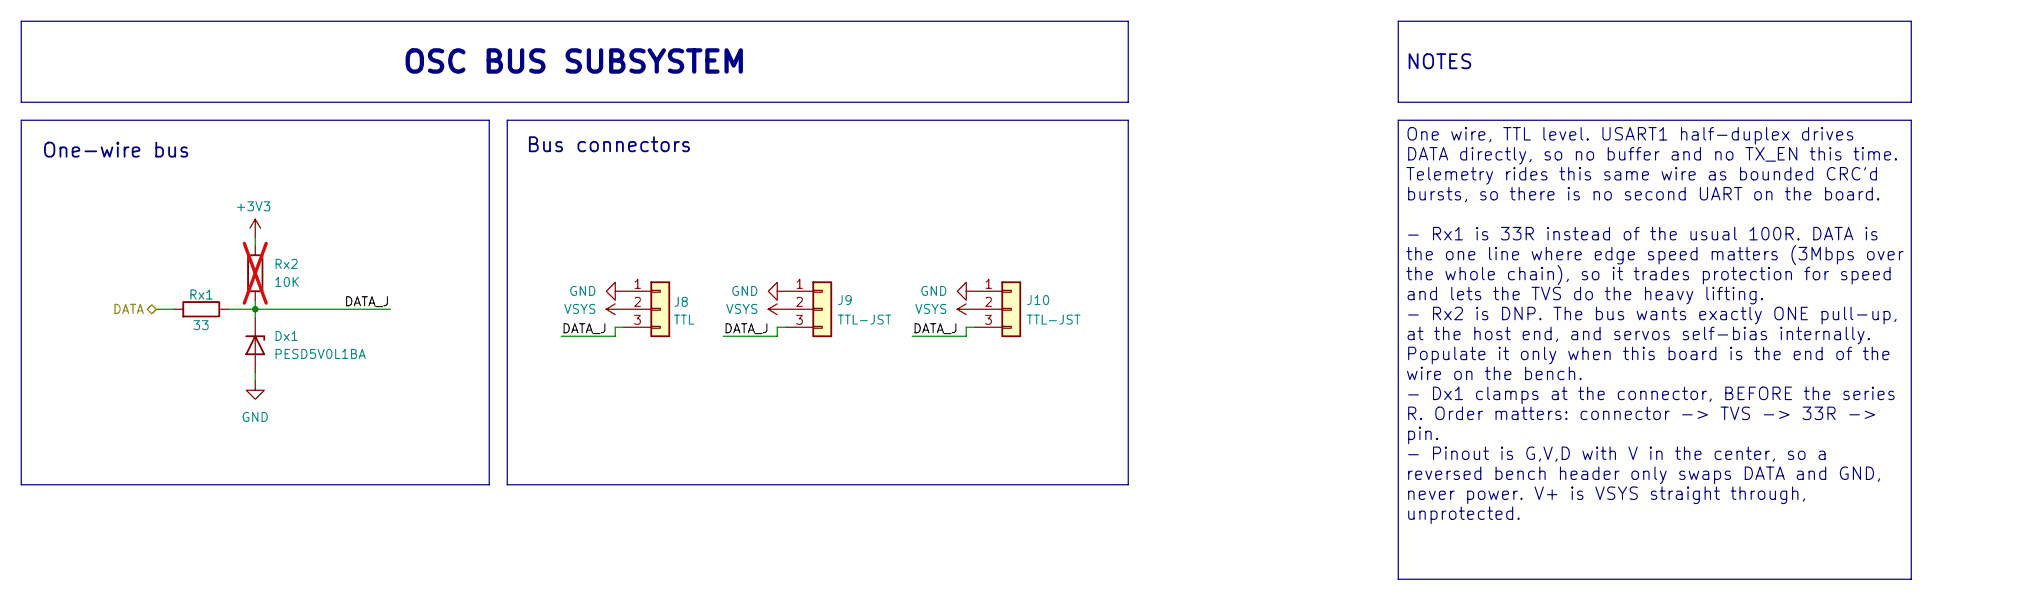
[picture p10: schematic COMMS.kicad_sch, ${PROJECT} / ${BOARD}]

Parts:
Dx1: PESD5V0L1BA; D_SOD-323_HandSoldering; LCSC C2687118
J8: TTL; PinHeader_1x03_P2.54mm_Vertical; LCSC C49257
J9, J10: TTL-JST; CONN-TH_B3B-PH-K-S; LCSC C131339
Rx1: 33; R_0603_1608Metric_Pad0.98x0.95mm_HandSolder; LCSC C108661
Rx2: 10K; R_0603_1608Metric_Pad0.98x0.95mm_HandSolder; LCSC C2906982; not fitted

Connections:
+3V3: Rx2.1; also elsewhere on the board
/COMMS/DATA: Rx1.2; also elsewhere on the board
/COMMS/DATA_J: Dx1.1 (K), J8.3, J9.3, J10.3, Rx1.1, Rx2.2
GND: Dx1.2 (A), J8.1, J9.1, J10.1; also elsewhere on the board
VSYS: J8.2, J9.2, J10.2; also elsewhere on the board

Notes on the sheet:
Bus connectors
One-wire bus
One wire, TTL level. USART1 half-duplex drives DATA directly, so no buffer and no TX_EN this time. Telemetry rides this same wire as bounded CRC'd bursts, so there is no second UART on the board. - Rx1 is 33R instead of the usual 100R. DATA is the one line where edge speed matters (3Mbps over the w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
OSC BUS SUBSYSTEM
NOTES

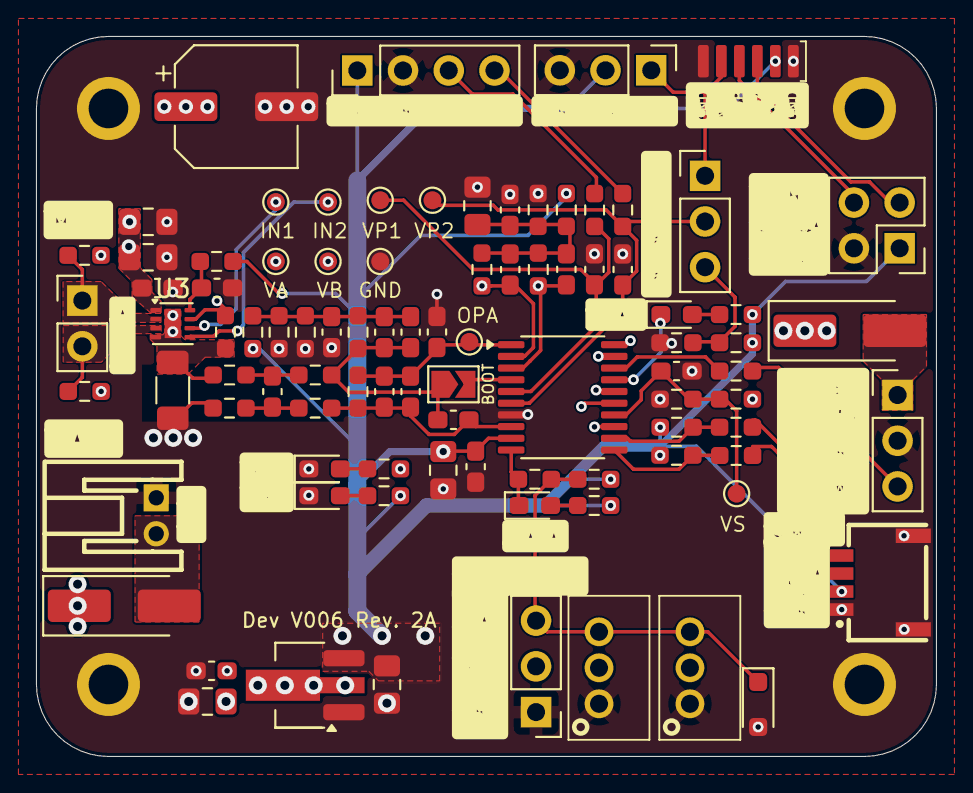
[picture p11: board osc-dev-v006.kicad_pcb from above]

Board: 6 copper layers, 50.0 x 40.0 mm, 99 parts (0 on the bottom side), 46 nets.

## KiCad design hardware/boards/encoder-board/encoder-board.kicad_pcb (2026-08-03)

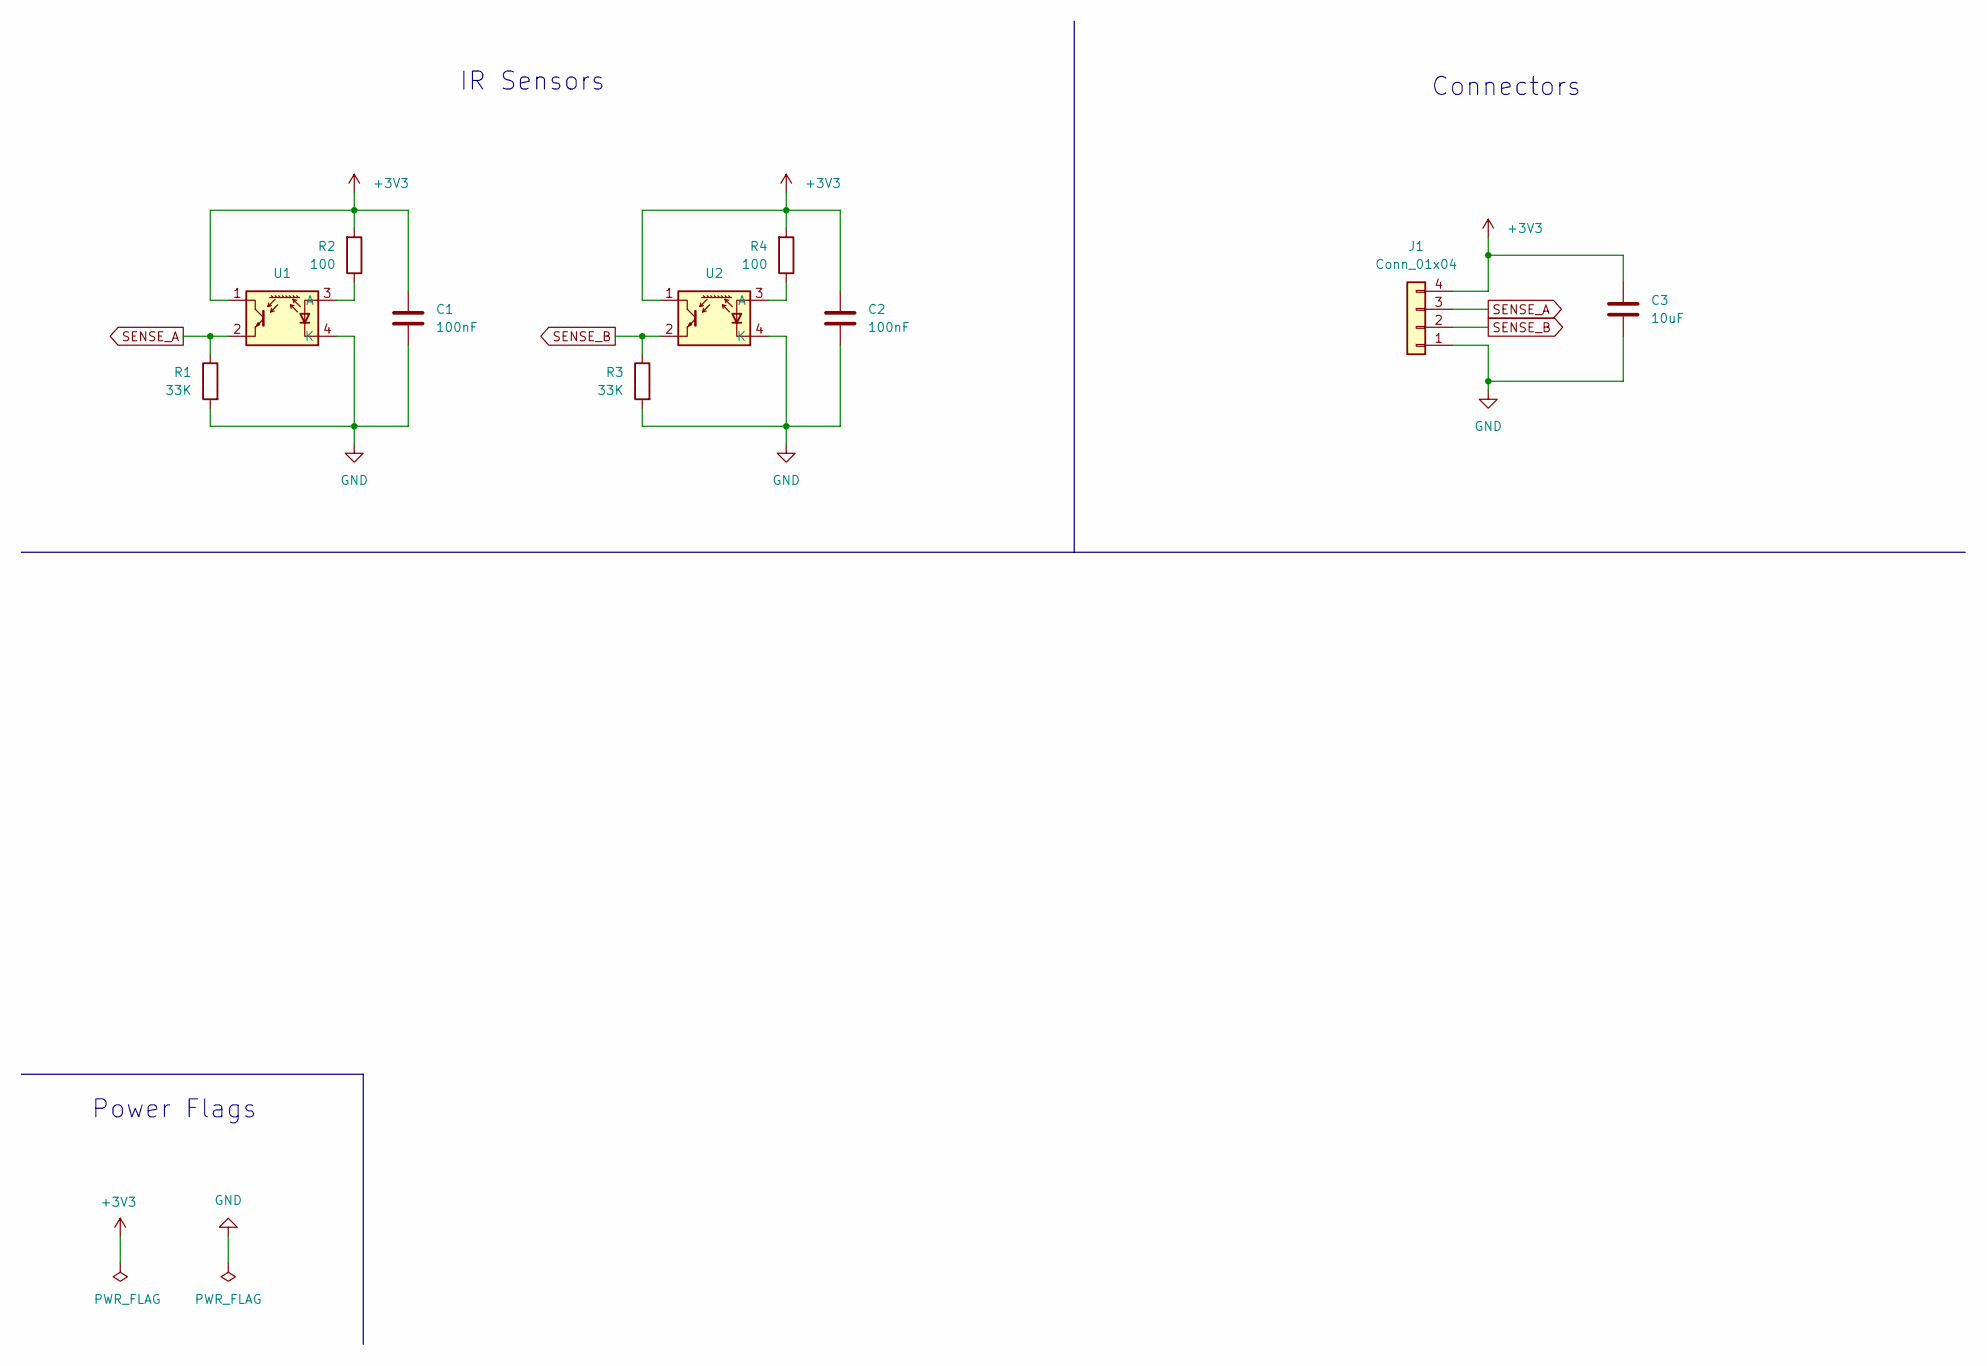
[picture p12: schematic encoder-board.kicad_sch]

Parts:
C1, C2: 100nF; C_0805_2012Metric_Pad1.18x1.45mm_HandSolder; LCSC C49678
C3: 10uF; C_0805_2012Metric_Pad1.18x1.45mm_HandSolder; LCSC C15850
J1: Conn_01x04; PinHeader_1x04_P2.54mm_Vertical; LCSC C780062
R1, R3: 33K; R_0805_2012Metric_Pad1.20x1.40mm_HandSolder; LCSC C17633
R2, R4: 100; R_0805_2012Metric_Pad1.20x1.40mm_HandSolder; LCSC C17408
U1, U2: ITR1204SR10A_TR(BY); OPTO-SMD-4_ITR1204SR10A; LCSC C475373

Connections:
+3V3: C1.1, C2.1, C3.1, J1.4, R2.2, R4.2, U1.1, U2.1
GND: C1.2, C2.2, C3.2, J1.1, R1.2, R3.2, U1.4 (K), U2.4 (K)
unnamed: R2.1, U1.3 (A)
unnamed: R4.1, U2.3 (A)
SENSE_A: J1.3, R1.1, U1.2
SENSE_B: J1.2, R3.1, U2.2

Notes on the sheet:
IR Sensors
Connectors
Power Flags

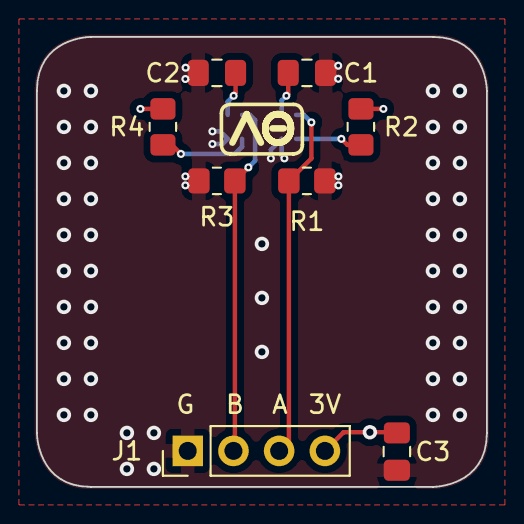
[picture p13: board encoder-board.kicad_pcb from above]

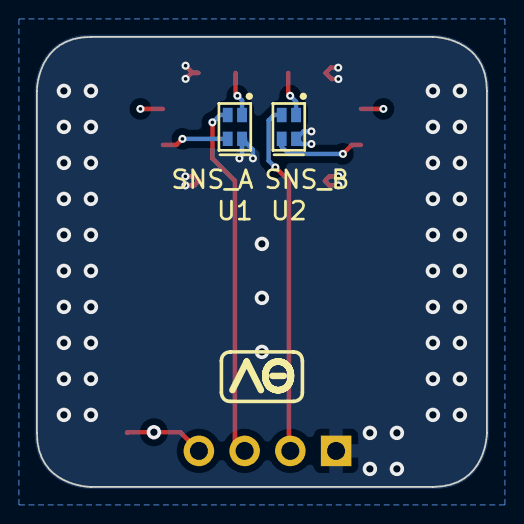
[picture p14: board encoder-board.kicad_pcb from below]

Board: 4 copper layers, 25.0 x 25.0 mm, 10 parts (2 on the bottom side), 6 nets.

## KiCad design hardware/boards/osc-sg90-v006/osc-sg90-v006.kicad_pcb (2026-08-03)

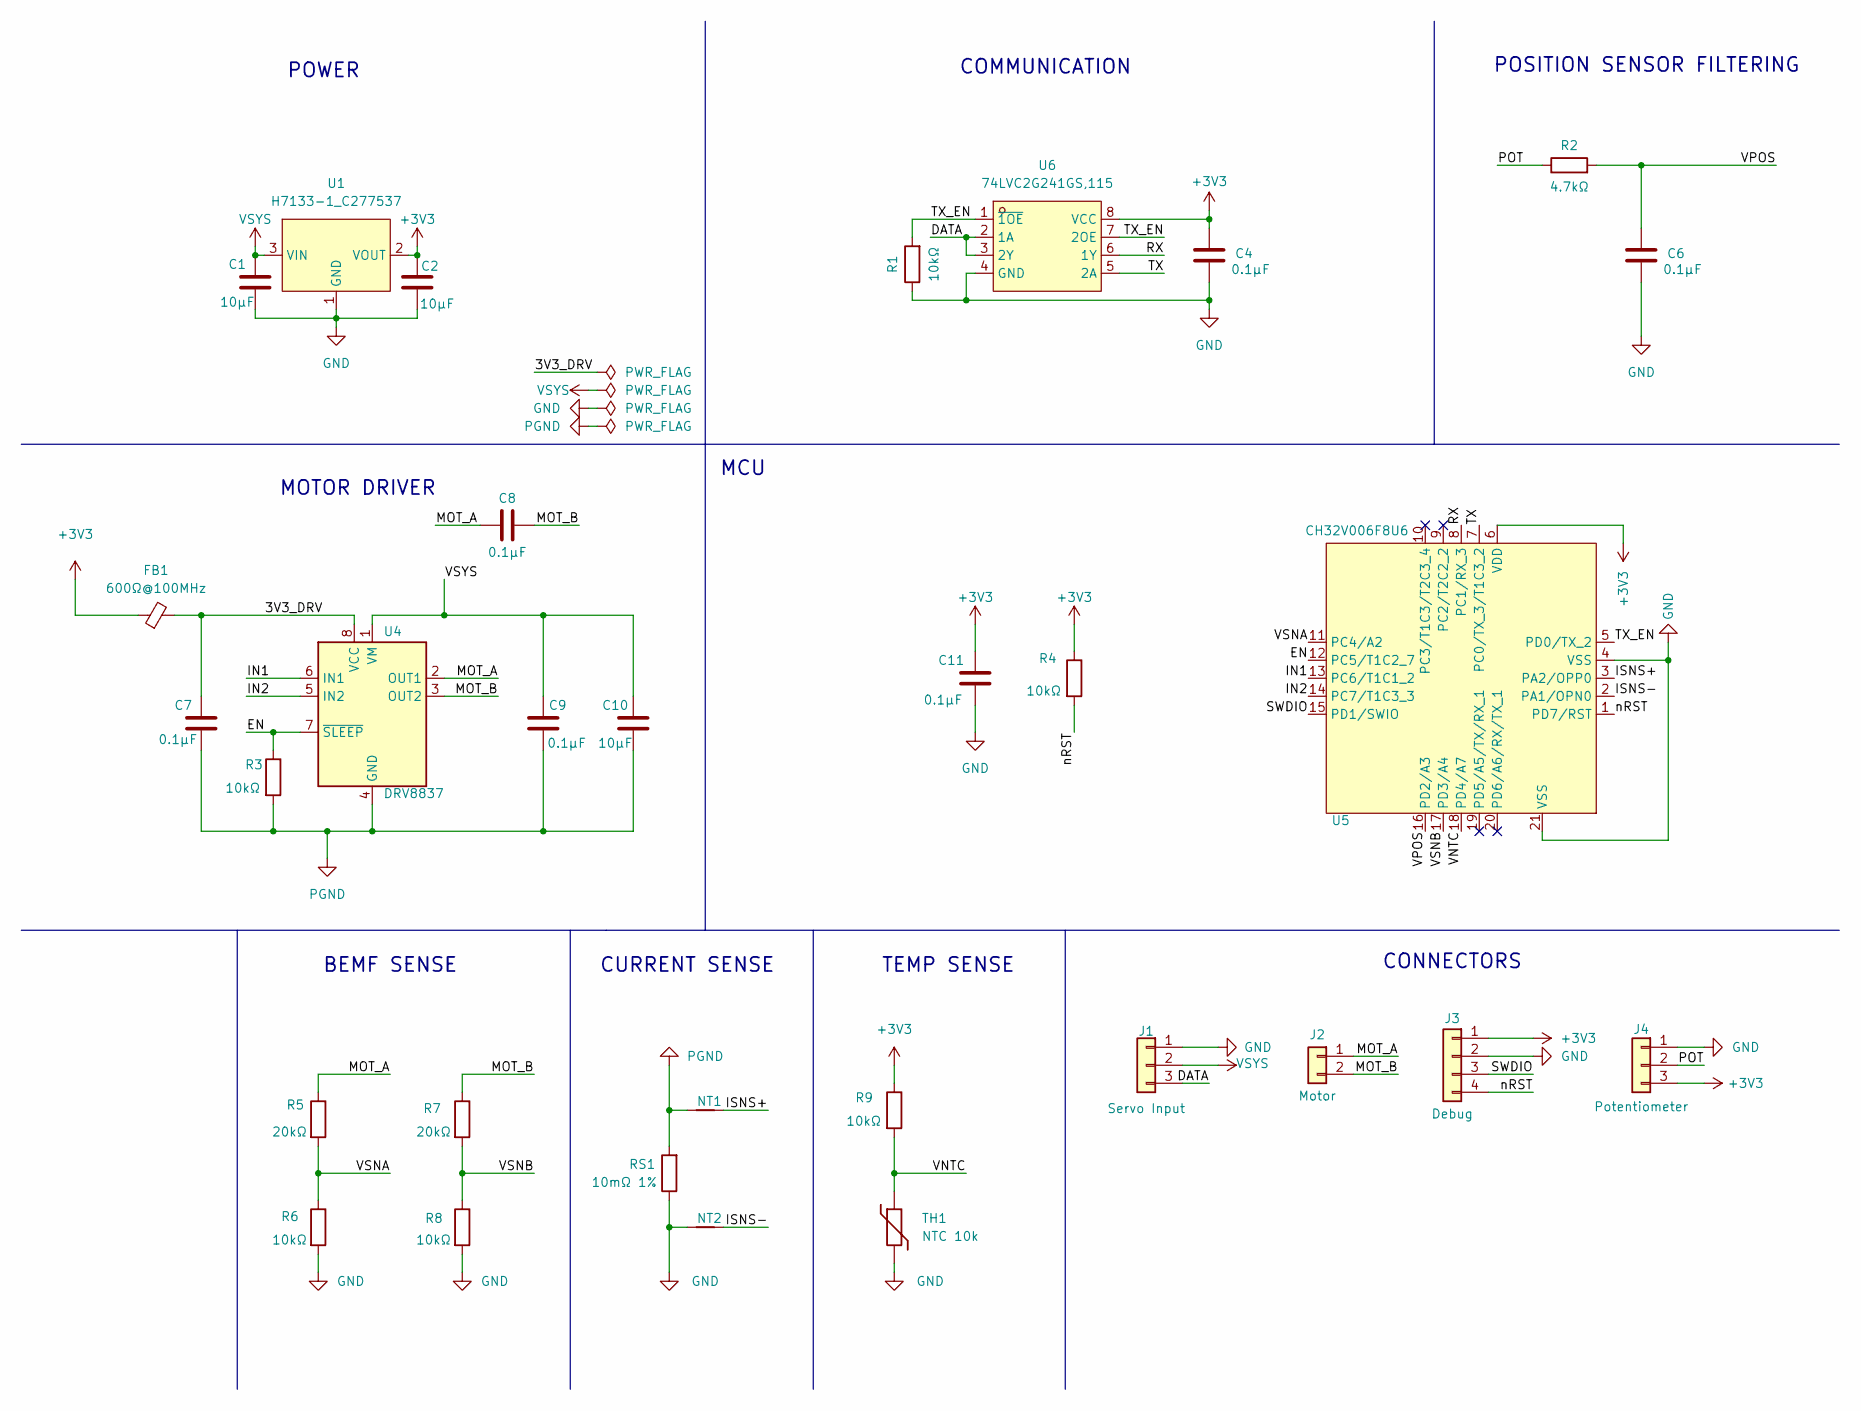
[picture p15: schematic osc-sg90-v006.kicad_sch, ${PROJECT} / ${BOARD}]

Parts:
C1, C2, C10: 10µF; C_0603_1608Metric; LCSC C96446
C4, C6, C7, C8, C9, C11: 0.1µF; C_0402_1005Metric; LCSC C1525
FB1: 600Ω@100MHz; L_0402_1005Metric; LCSC C76884
J1: Servo Input; Servo_Output_Pads
J2: Motor; Motor_Wire_Pads
J3: Debug; Debug_Pads_1x4_P1.27mm
J4: Potentiometer; Pot_Wire_Pads
NT1, NT2: NetTie_2; NetTie-2_SMD_0.127mm
R1, R3, R4, R6, R8, R9: 10kΩ; R_0402_1005Metric; LCSC C25744
R2: 4.7kΩ; R_0402_1005Metric; LCSC C25900
R5, R7: 20kΩ; R_0402_1005Metric; LCSC C25765
RS1: 10mΩ 1%; R_0805_2012Metric; LCSC C163089
TH1: NTC 10k; R_0402_1005Metric; LCSC C77131
U1: H7133-1_C277537; SOT-23-3_L2.9-W1.3-P1.90-LS2.4-BR; LCSC Part C277537
U4: DRV8837; Texas_DSG0008A_WSON-8-1EP_2x2mm_P0.5mm_EP0.9x1.6mm; LCSC C39159
U5: CH32V006F8U6; UQFN-20_L3.0-W3.0-P0.40-BL-EP1.7; LCSC C42431288
U6: 74LVC2G241GS,115; XSON-8_L1.4-W1.0-P0.35-S0.55-BL; LCSC C548628

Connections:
+3V3: C2.1, C4.1, C11.1, FB1.1, J3.1, J4.3, R4.1, R9.1, U1.2 (VOUT), U5.6 (VDD), U6.8 (VCC)
/3V3_DRV: C7.1, FB1.2, U4.8 (VCC)
/DATA: J1.3, U6.2 (1A), U6.3 (2Y)
/EN: R3.1, U4.7 (~SLEEP), U5.12 (PC5/T1C2_7)
/IN1: U4.6 (IN1), U5.13 (PC6/T1C1_2)
/IN2: U4.5 (IN2), U5.14 (PC7/T1C3_3)
/ISNS+: NT1.1, U5.3 (PA2/OPP0)
/ISNS-: NT2.1, U5.2 (PA1/OPN0)
/MOT_A: C8.1, J2.1, R5.1, U4.2 (OUT1)
/MOT_B: C8.2, J2.2, R7.1, U4.3 (OUT2)
/POT: J4.2, R2.1
/RX: U5.8 (PC1/RX_3), U6.6 (1Y)
/SWDIO: J3.3, U5.15 (PD1/SWIO)
/TX: U5.7 (PC0/TX_3/T1C3_2), U6.5 (2A)
/TX_EN: R1.2, U5.5 (PD0/TX_2), U6.1 (~1OE), U6.7 (2OE)
/VNTC: R9.2, TH1.1, U5.18 (PD4/A7)
/VPOS: C6.1, R2.2, U5.16 (PD2/A3)
/VSNA: R5.2, R6.1, U5.11 (PC4/A2)
/VSNB: R7.2, R8.1, U5.17 (PD3/A4)
/nRST: J3.4, R4.2, U5.1 (PD7/RST)
GND: C1.2, C2.2, C4.2, C6.2, C11.2, J1.1, J3.2, J4.1, NT2.2, R1.1, R6.2, R8.2, RS1.1, TH1.2, U1.1 (GND), U5.4 (VSS), U5.21 (VSS), U6.4 (GND)
PGND: C7.2, C9.2, C10.2, NT1.2, R3.2, RS1.2, U4.4 (GND), U4.9 (GND)
VSYS: C1.1, C9.1, C10.1, J1.2, U1.3 (VIN), U4.1 (VM)

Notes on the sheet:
POWER
MOTOR DRIVER
BEMF SENSE
CONNECTORS
TEMP SENSE
CURRENT SENSE
COMMUNICATION
MCU
POSITION SENSOR FILTERING

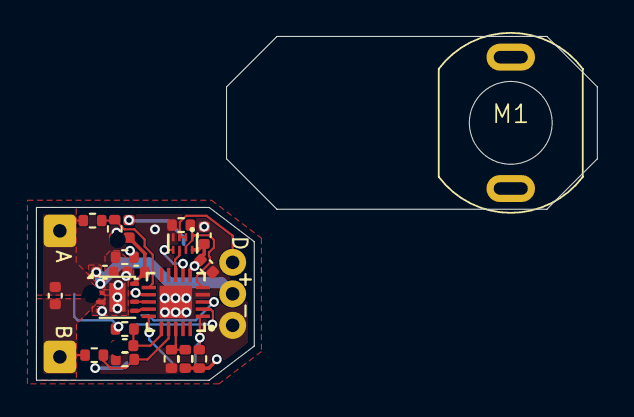
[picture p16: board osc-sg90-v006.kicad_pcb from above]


Board: 4 copper layers, 31.2 x 19.1 mm, 33 parts (8 on the bottom side), 23 nets.

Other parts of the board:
J4#2: Potentiometer; Pot_Wire_Pads
M1: SG90_Motor

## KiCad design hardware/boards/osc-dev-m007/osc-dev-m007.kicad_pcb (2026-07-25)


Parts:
H101, H102, H103, H104: MountingHole_Pad_MP; MountingHole_2.2mm_M2_ISO7380_Pad

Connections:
GND: H101.1 (1_1), H102.1 (1_1), H103.1 (1_1), H104.1 (1_1); also elsewhere on the board


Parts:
D901, D902: SS54; D_SMA_Handsoldering; LCSC C22452
J901: JST-PH-H; CONN-TH_S2B-PH-K-S-LF-SN; LCSC C173752
LED901: YELLOW; LED_0805_2012Metric; LCSC C2296
LED902: GREEN; LED_0805_2012Metric; LCSC C2297
R901: 22k; R_0805_2012Metric_Pad1.20x1.40mm_HandSolder; LCSC C17560
R902: 10k; R_0805_2012Metric_Pad1.20x1.40mm_HandSolder; LCSC C2907219

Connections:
+5V: R902.1; also elsewhere on the board
/POWER/LED_5V: LED902.2 (A), R902.2
/POWER/LED_VSYS: LED901.2 (A), R901.2
GND: J901.1, LED901.1 (K), LED902.1 (K); also elsewhere on the board
VBAT: D901.2 (A), J901.2
VPROG: D902.2 (A); also elsewhere on the board
VSYS: D901.1 (K), D902.1 (K), R901.1; also elsewhere on the board

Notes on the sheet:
POWER STATUS INDICATORS
POWER SOURCE OR-ING
BATTERY CONNECTOR JST-PH-2P
2S or 3S LiPo batteries
POWER SUBSYSTEM


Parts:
C1001: 1nF; C_0805_2012Metric_Pad1.18x1.45mm_HandSolder; LCSC C94121; not fitted
C1002, C1003: 0.1uF; C_0805_2012Metric_Pad1.18x1.45mm_HandSolder; LCSC C49678
J1001: NTC_EXT; PinHeader_1x02_P2.54mm_Vertical; LCSC C492401
J1002: ENC; PinHeader_1x03_P2.54mm_Vertical; LCSC C49257
J1003: POT; PinHeader_1x03_P2.54mm_Vertical; JLC Type Extended
JP1001: NTC_EXT_INT; PinHeader_1x03_P2.54mm_Vertical; LCSC C41425293
R1001: 10k; R_0805_2012Metric_Pad1.20x1.40mm_HandSolder; LCSC C2907219
R1002, R1003: 4.7k; R_0805_2012Metric_Pad1.20x1.40mm_HandSolder; LCSC C17673
TH1001: 10k 3950K; R_0805_2012Metric_Pad1.20x1.40mm_HandSolder; LCSC C49247662

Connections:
+5V: J1002.2, J1003.2, R1001.1; also elsewhere on the board
/SENSORS/ENC_IN: J1002.1, R1002.2
/SENSORS/NTC_EXT: J1001.1, JP1001.1 (A)
/SENSORS/NTC_INT: JP1001.3 (B), TH1001.1
/SENSORS/POT: J1003.1, R1003.2
ENC: C1001.2, R1002.1; also elsewhere on the board
GND: C1001.1, C1002.1, C1003.1, J1001.2, J1002.3, J1003.3, TH1001.2; also elsewhere on the board
NTC: C1003.2, JP1001.2 (C), R1001.2; also elsewhere on the board
POS: C1002.2, R1003.1; also elsewhere on the board

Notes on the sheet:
POTENTIOMETER
TEMPERATURE SENSOR
ENCODER CONNECTOR
SENSORS SUBSYSTEM


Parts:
J1201, J1202: Conn_01x06; PinHeader_1x06_P2.54mm_Vertical
TP1201, TP1202, TP1203, TP1204, TP1205, TP1206: TestPoint; TestPoint_Pad_D1.0mm

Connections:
+5V: J1201.1; also elsewhere on the board
DATA: J1202.1; also elsewhere on the board
DBG0: TP1201.1 (1_1); also elsewhere on the board
DBG1: TP1203.1 (1_1); also elsewhere on the board
DBG2: TP1205.1 (1_1); also elsewhere on the board
ENC: J1202.4; also elsewhere on the board
GND: J1201.2, J1201.4, J1201.6, J1202.2, TP1202.1 (1_1), TP1204.1 (1_1), TP1206.1 (1_1); also elsewhere on the board
LED: J1202.3; also elsewhere on the board
NTC: J1202.6; also elsewhere on the board
POS: J1202.5; also elsewhere on the board
VHREG: J1201.5; also elsewhere on the board
VSYS: J1201.3; also elsewhere on the board

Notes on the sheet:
Place near ISNS nodes
TEST POINTS
TESTPOINTS SUBSYSTEM


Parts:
C301: 470uF 25V; CP_Radial_D8.0mm_P3.50mm; LCSC C721169
J301: BLDC/BDC(A+B); CONN-TH_3P-P3.50_KF350-3.5-3P; LCSC C474893

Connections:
/BRIDGE/PH_A: J301.1; also elsewhere on the board
/BRIDGE/PH_B: J301.2; also elsewhere on the board
/BRIDGE/PH_C: J301.3; also elsewhere on the board
GND: C301.2; also elsewhere on the board
VSYS: C301.1; also elsewhere on the board

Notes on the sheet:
MOTOR BRIDGE SUBSYSTEM
BULK CAP
TP GLOBALS
MOTOR TERMINAL
Place close to shunt side GND
BRIDGE


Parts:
D1101: PESD5V0L1BA; D_SOD-323_HandSoldering; LCSC C2687118
J1101, J1102: JST-PH-V; CONN-TH_B3B-PH-K-S; JLC Type Extended
R1101: 33; R_0805_2012Metric_Pad1.20x1.40mm_HandSolder; LCSC C17634
R1102: 10k; R_0805_2012Metric_Pad1.20x1.40mm_HandSolder; LCSC C2907219; not fitted

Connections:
+5V: R1102.1; also elsewhere on the board
/BUS/BUS: R1101.2; also elsewhere on the board
DATA: D1101.1 (K), J1101.1, J1102.1, R1101.1, R1102.2; also elsewhere on the board
GND: D1101.2 (A), J1101.3, J1102.3; also elsewhere on the board
VSYS: J1101.2, J1102.2; also elsewhere on the board

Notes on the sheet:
DXL TTL CONNECTOR JST-PH VERTICAL
OSC BUS
OSC BUS SUBSYSTEM


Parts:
C201, C202: 2.2uF; C_0805_2012Metric_Pad1.18x1.45mm_HandSolder; JLC_Basic no
C203, C206, C209, C210: 0.1uF; C_0805_2012Metric_Pad1.18x1.45mm_HandSolder; JLC_Basic yes
C204, C205, C208: 10uF; C_1206_3216Metric_Pad1.33x1.80mm_HandSolder; JLC_Basic no
C207: 1uF; C_0805_2012Metric_Pad1.18x1.45mm_HandSolder; JLC_Basic yes
D201: STAT; LED_XL-1010RGBC-WS2812B_1x1mm; JLC_Basic no
J201: PROG; PinHeader_1x05_P2.54mm_Vertical; JLC_Basic no
R201: 0; R_0805_2012Metric_Pad1.20x1.40mm_HandSolder; JLC_Basic yes
R202: 10k; R_0805_2012Metric_Pad1.20x1.40mm_HandSolder; JLC_Basic yes
R203: 100; R_0805_2012Metric_Pad1.20x1.40mm_HandSolder; JLC_Basic yes
SW201: RESET; SW_SPST_TS-1088R_3.9x3.0mm; JLC_Basic no
U201: CH32M007E8U7; QFN-26_3x3mm_P0.4mm; JLC_Basic no

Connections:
+5V: C206.1, C207.1, C208.1, C210.1, D201.2 (VDD), R202.1, U201.13 (VDD); also elsewhere on the board
/BUS/BUS: U201.22 (TX_5); also elsewhere on the board
/MCU/SWDIO: J201.1, U201.5 (SWIO)
/MCU/nRST: C209.2, J201.5, R202.2, SW201.2, U201.2 (RST)
DBG0: U201.25 (PC2); also elsewhere on the board
DBG1: U201.12 (PA5); also elsewhere on the board
DBG2: U201.24 (PC1); also elsewhere on the board
ENC: U201.7 (A7); also elsewhere on the board
GATE_AH: U201.16 (HO1); also elsewhere on the board
GATE_AL: U201.17 (LO1); also elsewhere on the board
GATE_BH: U201.18 (HO2); also elsewhere on the board
GATE_BL: U201.19 (LO2); also elsewhere on the board
GATE_CH: U201.20 (HO3); also elsewhere on the board
GATE_CL: U201.21 (LO3); also elsewhere on the board
GND: C201.2, C202.2, C203.2, C204.2, C205.2, C206.2, C207.2, C208.2, C209.1, C210.2, D201.3 (VSS), J201.2, J201.4, SW201.1, U201.3 (VSS); also elsewhere on the board
ISNS1+: U201.10 (OPP1); also elsewhere on the board
ISNS2+: U201.6 (OPP2); also elsewhere on the board
ISNS-: U201.11 (OPN2); also elsewhere on the board
LED: R203.1, U201.23 (T2C3_01); also elsewhere on the board
NTC: U201.9 (A6); also elsewhere on the board
unnamed: D201.4 (DIN), R203.2
POS: U201.8 (A5); also elsewhere on the board
VHREG: C201.1, C202.1, R201.1, U201.14 (VHREG); also elsewhere on the board
VPROG: J201.3; also elsewhere on the board
VSNA: U201.1 (A2); also elsewhere on the board
VSNB: U201.4 (A3); also elsewhere on the board
VSNC: U201.26 (A1); also elsewhere on the board
VSYS: C203.1, C204.1, C205.1, R201.2, U201.15 (VHV); also elsewhere on the board

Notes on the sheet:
MICRO-CONTROLLER
RESET BUTTON
LED
POWER STAGE
MICRO-CONTROLLER SUBSYSTEM
WCH-LINKE CONN


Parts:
C501: 1nF; C_0805_2012Metric_Pad1.18x1.45mm_HandSolder; JLC_Basic yes; not fitted
NT501, NT502: NetTie_2; NetTie-2_SMD_0.127mm
R501: 0; R_0805_2012Metric_Pad1.20x1.40mm_HandSolder; JLC_Basic yes
R_SH501: 75m; R_1206_3216Metric_Pad1.30x1.75mm_HandSolder; JLC_Basic no
R_SH502: 150m; R_1206_3216Metric_Pad1.30x1.75mm_HandSolder; JLC_Basic no; not fitted

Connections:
/BRIDGE/HALFBRIDGE1/LEG: NT501.1, R_SH501.1, R_SH502.1; also elsewhere on the board
/BRIDGE/SHUNT1/ISNS_K: NT501.2, R501.1
GND: NT502.1, R_SH501.2, R_SH502.2; also elsewhere on the board
ISNS1+: C501.1, R501.2; also elsewhere on the board
ISNS-: C501.2, NT502.2; also elsewhere on the board

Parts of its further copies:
C701: 1nF; C_0805_2012Metric_Pad1.18x1.45mm_HandSolder; JLC_Basic yes; not fitted
NT701, NT702: NetTie_2; NetTie-2_SMD_0.127mm
R701: 0; R_0805_2012Metric_Pad1.20x1.40mm_HandSolder; JLC_Basic yes
R_SH701: 75m; R_1206_3216Metric_Pad1.30x1.75mm_HandSolder; JLC_Basic no
R_SH702: 150m; R_1206_3216Metric_Pad1.30x1.75mm_HandSolder; JLC_Basic no; not fitted

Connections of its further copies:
/BRIDGE/HALFBRIDGE2/LEG: NT701.1, R_SH701.1, R_SH702.1; also elsewhere on the board
/BRIDGE/SHUNT2/ISNS_K: NT701.2, R701.1
GND: NT702.1, R_SH701.2, R_SH702.2; also elsewhere on the board
ISNS2+: C701.1, R701.2; also elsewhere on the board
ISNS-: C701.2, NT702.2; also elsewhere on the board

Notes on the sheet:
RC FILTER (DNP)
SHUNT SUBSYSTEM
SHUNT

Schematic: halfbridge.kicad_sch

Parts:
C401: 10uF; C_1206_3216Metric_Pad1.33x1.80mm_HandSolder; JLC_Basic no
C402: 1nF; C_0805_2012Metric_Pad1.18x1.45mm_HandSolder; JLC_Basic yes
C403: 1nF; C_0805_2012Metric_Pad1.18x1.45mm_HandSolder; JLC_Basic yes; not fitted
Q401: SIL3724A-TP; SOT-23-6; JLC_Basic no
R401, R402: 0; R_0805_2012Metric_Pad1.20x1.40mm_HandSolder; JLC_Basic yes
R403, R404: 100k; R_0805_2012Metric_Pad1.20x1.40mm_HandSolder; JLC_Basic yes
R405: 20k; R_0805_2012Metric_Pad1.20x1.40mm_HandSolder; JLC_Basic yes
R406: 10k; R_0805_2012Metric_Pad1.20x1.40mm_HandSolder; JLC_Basic yes
R407: 10; R_0805_2012Metric_Pad1.20x1.40mm_HandSolder; JLC_Basic yes; not fitted

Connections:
/BRIDGE/HALFBRIDGE1/G_H: Q401.3 (G), R401.2, R403.1
/BRIDGE/HALFBRIDGE1/G_L: Q401.1 (G), R402.2, R404.2
/BRIDGE/HALFBRIDGE1/LEG: Q401.5 (S); also elsewhere on the board
/BRIDGE/HALFBRIDGE1/SNUB: C403.1, R407.2
/BRIDGE/PH_A: Q401.4 (D), Q401.6 (D), R405.1, R407.1; also elsewhere on the board
GATE_AH: R401.1; also elsewhere on the board
GATE_AL: R402.1; also elsewhere on the board
GND: C401.2, C402.2, C403.2, R404.1, R406.2; also elsewhere on the board
VSNA: C402.1, R405.2, R406.1; also elsewhere on the board
VSYS: C401.1, Q401.2 (S), R403.2; also elsewhere on the board

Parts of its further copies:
C601, C801: 10uF; C_1206_3216Metric_Pad1.33x1.80mm_HandSolder; JLC_Basic no
C602, C802: 1nF; C_0805_2012Metric_Pad1.18x1.45mm_HandSolder; JLC_Basic yes
C603, C803: 1nF; C_0805_2012Metric_Pad1.18x1.45mm_HandSolder; JLC_Basic yes; not fitted
Q601, Q801: SIL3724A-TP; SOT-23-6; JLC_Basic no
R601, R602, R801, R802: 0; R_0805_2012Metric_Pad1.20x1.40mm_HandSolder; JLC_Basic yes
R603, R604, R803, R804: 100k; R_0805_2012Metric_Pad1.20x1.40mm_HandSolder; JLC_Basic yes
R605, R805: 20k; R_0805_2012Metric_Pad1.20x1.40mm_HandSolder; JLC_Basic yes
R606, R806: 10k; R_0805_2012Metric_Pad1.20x1.40mm_HandSolder; JLC_Basic yes
R607, R807: 10; R_0805_2012Metric_Pad1.20x1.40mm_HandSolder; JLC_Basic yes; not fitted

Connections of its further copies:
/BRIDGE/HALFBRIDGE2/G_H: Q601.3 (G), R601.2, R603.1
/BRIDGE/HALFBRIDGE2/G_L: Q601.1 (G), R602.2, R604.2
/BRIDGE/HALFBRIDGE2/LEG: Q601.5 (S); also elsewhere on the board
/BRIDGE/HALFBRIDGE2/SNUB: C603.1, R607.2
/BRIDGE/HALFBRIDGE3/G_H: Q801.3 (G), R801.2, R803.1
/BRIDGE/HALFBRIDGE3/G_L: Q801.1 (G), R802.2, R804.2
/BRIDGE/HALFBRIDGE3/SNUB: C803.1, R807.2
/BRIDGE/PH_B: Q601.4 (D), Q601.6 (D), R605.1, R607.1; also elsewhere on the board
/BRIDGE/PH_C: Q801.4 (D), Q801.6 (D), R805.1, R807.1; also elsewhere on the board
GATE_BH: R601.1; also elsewhere on the board
GATE_BL: R602.1; also elsewhere on the board
GATE_CH: R801.1; also elsewhere on the board
GATE_CL: R802.1; also elsewhere on the board
GND: C601.2, C602.2, C603.2, C801.2, C802.2, C803.2, Q801.5 (S), R604.1, R606.2, R804.1, R806.2; also elsewhere on the board
VSNB: C602.1, R605.2, R606.1; also elsewhere on the board
VSNC: C802.1, R805.2, R806.1; also elsewhere on the board
VSYS: C601.1, C801.1, Q601.2 (S), Q801.2 (S), R603.2, R803.2; also elsewhere on the board

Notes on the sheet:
HALF-BRIDGE
HALF-BRIDGE SUBSYSTEM
VOLTAGE SENSE
RC SNUBBER


Board: 6 copper layers, 50.0 x 50.0 mm, 99 parts (0 on the bottom side), 52 nets.

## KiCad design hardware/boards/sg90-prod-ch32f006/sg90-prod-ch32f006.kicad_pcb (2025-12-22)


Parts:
C1, C8: 10µF; C_0603_1608Metric
C2, C3: 1µF; C_0402_1005Metric
C4, C5, C6, C7, C9: 0.1µF; C_0402_1005Metric
D1: PESD5V0L1UL; D_SOD-882
FB1: 600Ω@100MHz; L_0603_1608Metric
J1: Servo Input; Servo_Output_Pads
J2: Motor; Motor_Wire_Pads
J3: Debug; Debug_Pads_1x4_P1.27mm
J4: Potentiometer; Pot_Wire_Pads
NT1, NT2, NT3: NetTie_2; NetTie-2_SMD_0.2mm
Q1: AO3401A; SOT-23
R1: 1kΩ; R_0402_1005Metric
R2: 4.7kΩ; R_0402_1005Metric
R3, R5, R6, R8, R10, R12: 10kΩ; R_0402_1005Metric
R4: 0.1Ω 1%; R_1206_3216Metric
R7, R9, R11: 20kΩ; R_0402_1005Metric
TH1: NTC 10k; R_0402_1005Metric
U1: TPAP2210K-3.3TRG1; SOT-23-5_L2.9-W1.6-P0.95-LS2.8-BR; LCSC Part C49190789
U2: SN74LVC1G07DRLR_C19829624; SOT-553-5_L1.6-W1.2-P0.50-LS1.6-BL; LCSC Part C19829624
U3: DRV8837DSGR-JSM; WSON-8-1EP_2x2mm_P0.5mm_EP0.9x1.6mm; LCSC C22447132
U4: CH32V006F8U6; UQFN-20_L3.0-W3.0-P0.40-BL-EP1.7; LCSC Part C42431288

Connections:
+3.3V: C3.1, C4.1, C9.1, FB1.1, J3.1, J4.1, R1.1, R5.1, R6.1, U1.5 (VOUT), U2.5 (VCC), U4.6 (VDD)
/3V3_DRV: C6.1, FB1.2, U3.8 (VCC)
/DATA: D1.1 (K), J1.3, NT1.2, R1.2, U2.4 (Y)
/EN: R3.1, U3.7 (~SLEEP), U4.12 (PC5/T1C2_/T1/T2/TX_/SCK)
/IN1: U3.6 (IN1), U4.13 (PC6/T1C3_/T1/RX_/MOSI)
/IN2: U3.5 (IN2), U4.14 (PC7/T1C4_/T1/T2/MISO)
/ISNS+: NT2.1, U4.3 (PA2/T1/T2/U2TX_/OPP0/XO/A0), U4.20 (PD6/T2/RX/TX_/MOSI_/A6)
/ISNS-: NT3.1, U4.2 (PA1/T1/T2/OPN0/XI/A1)
/OUTA: J2.1, R9.1, U3.2 (OUT1)
/OUTB: J2.2, R11.1, U3.3 (OUT2)
/POT: J4.2, R2.1
/RX: NT1.1, U4.8 (PC1/T1C2N_/T2/RX_/SDA/NSS)
/SWDIO: J3.3, U4.15 (PD1/SWIO/T1/SCL_/RX_/OPP3)
/TX: U2.2 (A), U4.7 (PC0/T1C1N_/T1/T2/TX_/MOSI_)
/VINS: R7.2, R8.1, U4.18 (PD4/T1/T2/SCK_/OPO0/A7)
/VNTC: R5.2, TH1.1, U4.19 (PD5/T2/TX/RX_/MISO_/A5)
/VPOS: C5.1, R2.2, U4.16 (PD2/T1/T2/U2TX_/A3)
/VSNA: R9.2, R10.1, U4.11 (PC4/T1C1_/T1/MCO/A2)
/VSNB: R11.2, R12.1, U4.17 (PD3/T1/T2/U2RX_/NSS_/OPP2/A4)
/VSYS: C1.1, C2.1, C7.1, C8.1, Q1.3 (D), R7.1, U1.1 (VIN), U1.3 (EN), U3.1 (VM)
/nRST: J3.4, R6.2, U4.1 (PD7/RST/T2C4/OPP1/PA4/U2TX_/OPN2)
GND: C1.2, C2.2, C3.2, C4.2, C5.2, C9.2, D1.2 (A), J1.1, J3.2, J4.3, NT3.2, Q1.1 (G), R4.1, R8.2, R10.2, R12.2, TH1.2, U1.2 (GND), U2.3 (GND), U4.4 (VSS), U4.21 (VSS)
PGND: C6.2, C7.2, C8.2, NT2.2, R3.2, R4.2, U3.4 (GND), U3.9 (GND)
VIN: J1.2, Q1.2 (S)

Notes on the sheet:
VSYS SENSE
POWER
MOTOR DRIVER
BEMF SENSE
CONNECTORS
TEMP SENSE
CURRENT SENSE
COMMUNICATION
MCU
POSITION SENSOR FILTERING



Board: 6 copper layers, 12.5 x 10.0 mm, 36 parts (11 on the bottom side), 24 nets.

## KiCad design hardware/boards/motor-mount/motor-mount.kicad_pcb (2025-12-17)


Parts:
C1: 47uF; C_1206_3216Metric; not fitted
J1: PinHeader_1x02_P2.54mm_Vertical
M1: Motor_DC; SG90_Motor

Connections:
+VDC: C1.1, J1.1, M1.1 (+)
-VDC: C1.2, J1.2, M1.2 (-)


Board: 2 copper layers, 15.0 x 17.8 mm, 3 parts (1 on the bottom side), 2 nets.

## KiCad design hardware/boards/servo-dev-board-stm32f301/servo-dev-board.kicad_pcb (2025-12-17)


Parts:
C1, C2, C3, C6, C7: 0.1uF; C_0402_1005Metric; LCSC C1525
C4, C5, C10: 1uF; C_0402_1005Metric; LCSC C52923
C8: 4.7uF; C_0603_1608Metric; LCSC C19666
C9: 10nF; C_0402_1005Metric; LCSC C15195
C11: 22uF; C_0603_1608Metric; LCSC C59461
CL1, CL2: 12pF; C_0402_1005Metric; LCSC C1547
H1, H2: Conn_01x08_Pin; PinHeader_1x08_P2.54mm_Vertical; LCSC C6332201
J1: USB_B_Micro; USB_Micro-B_Amphenol_10118194-0001LF_Horizontal; LCSC C428495
J2: Conn_01x05_MountingPin; JST_ZH_B5B-ZR-SM4-TF_1x05-1MP_P1.50mm_Vertical; LCSC C265440
J3, J4: Conn_01x04_MountingPin; JST_SH_BM04B-SRSS-TB_1x04-1MP_P1.00mm_Vertical; LCSC C160390
J5: Conn_02x05_Odd_Even; IDC-TH_10P-P1.27-X1270WV-2X05A-6TV01; LCSC C2962225
L1: 1kΩ@100Mhz; L_0402_1005Metric; LCSC C76883
LED1: RED; LED_0603_1608Metric; LCSC C2286
MH1, MH2, MH3, MH4: MountingHole_Pad_MP; MountingHole_2.2mm_M2_Pad_Via
R1, R2, R3, R4, R5, R6: 4K7; R_0402_1005Metric; LCSC C25792
R7: 1K5; R_0402_1005Metric; LCSC C25867
SW1, SW2: SW_Push; SW_SPST_PTS810; LCSC C221895
U2: SSP7615-33DFR; UDFN-4-1EP_1x1mm_P0.65mm_EP0.48x0.48mm; LCSC Part C3011523
U3: STM32F301K8Ux; QFN-32-1EP_5x5mm_P0.5mm_EP3.45x3.45mm; LCSC C111684
U4: DRV8231ADSG; WSON-8-1EP_2x2mm_P0.5mm_EP0.9x1.6mm
Y1: 16MHz 9pF; Crystal_SMD_3225-4Pin_3.2x2.5mm; LCSC C13738

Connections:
+3V3: C4.2, C6.2, C7.2, C8.2, H2.2, J3.2, J4.4, J5.1, L1.2, R1.2, R2.1, R3.1, R4.2, R5.1, SW2.1, U2.1 (VOUT), U3.1 (VDD), U3.17 (VDD), U4.4 (VREF)
+5V: C1.2, C5.2, C11.2, H2.1, J1.1 (VBUS), U2.3 (EN), U2.4 (VIN), U4.5 (VM)
/BOOT0: C3.1, R6.1, SW2.2, U3.31 (BOOT0)
/I2C1_SCL: J3.4, R3.2, U3.29 (PB6)
/I2C1_SDA: J3.3, R2.2, U3.30 (PB7)
/ISNS: R7.1, U3.8 (PA1), U4.1 (IPROPI)
/JTCK_SWCLK: J5.4, U3.24 (PA14)
/JTDI: J5.8, U3.25 (PA15)
/JTDO_SWO: J5.6, U3.26 (PB3)
/JTMS_SWDIO: J5.2, U3.23 (PA13)
/M1: J2.4, U4.6 (OUT1)
/M2: J2.5, U4.8 (OUT2)
/NJTRST: J5.10, U3.27 (PB4)
/NRST: C2.2, SW1.1, U3.4 (NRST)
/OSC+: CL1.1, U3.3 (PF1), Y1.1
/OSC-: CL2.2, U3.2 (PF0), Y1.3
/PA2: H1.1, U3.9 (PA2)
/PA3: H1.2, U3.10 (PA3)
/PA4: H1.3, U3.11 (PA4)
/PA5: H1.4, U3.12 (PA5)
/PA6: H1.5, U3.13 (PA6)
/PA7: H1.6, U3.14 (PA7)
/PA12: H2.7, U3.22 (PA12)
/PB0: H1.7, U3.15 (PB0)
/PB5: H2.6, U3.28 (PB5)
/POT: J2.1, U3.7 (PA0)
/PWM1: U3.18 (PA8), U4.3 (IN1)
/PWM2: U3.21 (PA11), U4.2 (IN2)
/UART1_RX: J4.1, R1.1, U3.20 (PA10)
/UART1_TX: J4.3, R4.1, U3.19 (PA9)
/VREF: C9.2, C10.2, H2.4, J2.2, L1.1, U3.5 (VDDA)
GND: C1.1, C2.1, C3.2, C4.1, C5.1, C6.1, C7.1, C8.1, C9.1, C10.1, C11.1, CL1.2, CL2.1, H1.8, H2.3, H2.5, H2.8, J1.5 (GND), J1.6 (Shield), J2.3, J2.MP (MountPin), J3.1, J3.MP (MountPin), J4.2, J4.MP (MountPin), J5.3, J5.5, J5.9, LED1.1 (K), MH1.1, MH2.1, MH3.1, MH4.1, R6.2, R7.2, SW1.2, U2.2 (GND), U2.5 (EP), U3.6 (VSSA), U3.16 (VSS), U3.32 (VSS), U3.33 (VSS), U4.7 (GND), U4.9 (GND), Y1.2, Y1.4
unnamed: LED1.2 (A), R5.2

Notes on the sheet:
Cortex 10-pin JTAG/SWD (0.05" pitch)
Dec 31st, 2024
Reset Button
Smart Servo Development Board
STM32F301 Micro Controller
Boot Select Button
Servo Connector
Bulk & Decoupling Capacitors
GPIO Female Headers
1.0.0-pre
5V to 3.3V Power Regulator (LDO)
LED Indicators
Micro USB +5V
M2 Screw Mounting Holes
UART - JST SH 4 Pin
STEMMA QT / Qwiic JST (I2C)
HSE Crystal Oscillator
lib:KEY-SMD_4P-L4.2-W3.2-P2.20-LS4.6
Motor Driver With Current Sensing
This capacitor must be placed as close to the NRST pin as possible.
Place 0.1uF capacitors close to VDD_1 & VDD_2. 4.7uF capacitor is Bulk Capacitor. VREF is needed to provider better ADC results. L1 is a ferrite bead with 1kΩ@100Mhz.
Limit current to 1.46A
Estimated Cs = 3pF Cl = 9pF Cl1 = Cl2 = (Cl - Cs) * 2 = 12pF



Board: 4 copper layers, 51.5 x 26.5 mm, 39 parts (2 on the bottom side), 33 nets.

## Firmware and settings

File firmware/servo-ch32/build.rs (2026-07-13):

use std::collections::{BTreeMap, BTreeSet};
use std::env;
use std::error::Error;
use std::fmt::Write as FmtWrite;
use std::fs;
use std::path::{Path, PathBuf};

use ch32_metapac::metadata::METADATA;

fn main() -> Result<(), Box<dyn Error>> {
    let out = PathBuf::from(env::var_os("OUT_DIR").unwrap());

    for p in METADATA.peripherals {
        if let Some(regs) = &p.registers {
            println!("cargo:rustc-cfg={}_{}", regs.kind, regs.version);
        }
    }

    generate_pin_and_usart_mapping(&out)?;

    // Ship the saved-config linker fragment (`INCLUDE osc-config.x` in a
    // board's memory.x); the link-search path propagates to the board link.
    fs::copy("osc-config.x", out.join("osc-config.x"))?;
    println!("cargo:rustc-link-search={}", out.display());
    println!("cargo:rerun-if-changed=osc-config.x");

    println!("cargo:rerun-if-changed=build.rs");
    Ok(())
}

fn port_index(port: char) -> usize {
    (port as usize) - ('A' as usize)
}

fn generate_pin_and_usart_mapping(out: &Path) -> Result<(), Box<dyn Error>> {
    let mut code = String::new();

    // discriminant = (port_index << 5) | pin_number.
    let mut pins: Vec<(char, u8)> = Vec::new();
    for p in METADATA.peripherals {
        if let Some(regs) = &p.registers
            && regs.kind == "gpio"
        {
            let port = p.name.chars().nth(4).unwrap();
            let pins_per_port: u8 = match regs.version {
                "v0" => 8,
                "v3" => 16,
                "x0" => 24,
                _ => 8,
            };
            for n in 0..pins_per_port {
                pins.push((port, n));
            }
        }
    }
    pins.sort();

    writeln!(code, "#[derive(Copy, Clone, Debug, PartialEq, Eq)]")?;
    writeln!(code, "#[repr(u8)]")?;
    writeln!(code, "#[allow(dead_code)]")?;
    writeln!(code, "pub enum Pin {{")?;
    for &(port, num) in &pins {
        let discrim = (port_index(port) << 5) | (num as usize);
        writeln!(code, "    P{port}{num} = {discrim:#04x},")?;
    }
    writeln!(code, "}}")?;
    writeln!(code)?;

    writeln!(code, "impl Pin {{")?;
    writeln!(code, "    #[inline(always)]")?;
    writeln!(
        code,
        "    pub const fn port_index(self) -> usize {{ (self as u8 >> 5) as usize }}"
    )?;
    writeln!(code)?;
    writeln!(code, "    #[inline(always)]")?;
    writeln!(
        code,
        "    pub const fn pin_number(self) -> usize {{ (self as u8 & 0x1f) as usize }}"
    )?;
    writeln!(code)?;
    writeln!(code, "    #[inline(always)]")?;
    writeln!(
        code,
        "    pub fn gpio_regs(self) -> ch32_metapac::gpio::Gpio {{ ch32_metapac::GPIO(self.port_index()) }}"
    )?;
    writeln!(code, "}}")?;
    writeln!(code)?;

    struct RemapGroup {
        peripheral_name: String,
        tx_pin: Option<String>,
        rx_pin: Option<String>,
    }

    let mut groups: BTreeMap<(String, u8), RemapGroup> = BTreeMap::new();

    for p in METADATA.peripherals {
        if let Some(regs) = &p.registers {
            if regs.kind != "usart" {
                continue;
            }
            for pin_entry in p.pins {
                let remap_val = match pin_entry.remap {
                    Some(r) => r,
                    None => continue,
                };
                let key = (p.name.to_string(), remap_val);
                let group = groups.entry(key).or_insert_with(|| RemapGroup {
                    peripheral_name: p.name.to_string(),
                    tx_pin: None,
                    rx_pin: None,
                });
                match pin_entry.signal {
                    "TX" => group.tx_pin = Some(pin_entry.pin.to_string()),
                    "RX" => group.rx_pin = Some(pin_entry.pin.to_string()),
                    _ => {}
                }
            }
        }
    }

    writeln!(code, "#[derive(Copy, Clone, Debug, PartialEq, Eq)]")?;
    writeln!(code, "#[allow(dead_code)]")?;
    writeln!(code, "pub enum UsartMapping {{")?;
    for ((peri, remap), group) in &groups {
        let variant = format!("{}Remap{}", capitalize_peripheral(peri), remap);
        let tx = group.tx_pin.as_deref().unwrap_or("?");
        let rx = group.rx_pin.as_deref().unwrap_or("?");
        writeln!(code, "    /// {peri} remap {remap}: TX={tx}, RX={rx}")?;
        writeln!(code, "    {variant},")?;
    }
    writeln!(code, "}}")?;
    writeln!(code)?;

    writeln!(code, "impl UsartMapping {{")?;

    writeln!(code, "    pub const fn tx_pin(self) -> Pin {{")?;
    writeln!(code, "        match self {{")?;
    for ((peri, remap), group) in &groups {
        let variant = format!("{}Remap{}", capitalize_peripheral(peri), remap);
        let tx = group.tx_pin.as_ref().expect("USART mapping missing TX pin");
        writeln!(code, "            UsartMapping::{variant} => Pin::{tx},")?;
    }
    writeln!(code, "        }}")?;
    writeln!(code, "    }}")?;
    writeln!(code)?;

    writeln!(code, "    pub const fn rx_pin(self) -> Pin {{")?;
    writeln!(code, "        match self {{")?;
    for ((peri, remap), group) in &groups {
        let variant = format!("{}Remap{}", capitalize_peripheral(peri), remap);
        let rx = group.rx_pin.as_ref().expect("USART mapping missing RX pin");
        writeln!(code, "            UsartMapping::{variant} => Pin::{rx},")?;
    }
    writeln!(code, "        }}")?;
    writeln!(code, "    }}")?;
    writeln!(code)?;

    writeln!(code, "    pub const fn remap_value(self) -> u8 {{")?;
    writeln!(code, "        match self {{")?;
    for (peri, remap) in groups.keys() {
        let variant = format!("{}Remap{}", capitalize_peripheral(peri), remap);
        writeln!(code, "            UsartMapping::{variant} => {remap},")?;
    }
    writeln!(code, "        }}")?;
    writeln!(code, "    }}")?;
    writeln!(code)?;

    writeln!(
        code,
        "    pub const fn regs(self) -> ch32_metapac::usart::Usart {{"
    )?;
    writeln!(code, "        match self {{")?;
    for ((peri, remap), group) in &groups {
        let variant = format!("{}Remap{}", capitalize_peripheral(peri), remap);
        let peri_const = &group.peripheral_name;
        writeln!(
            code,
            "            UsartMapping::{variant} => ch32_metapac::{peri_const},"
        )?;
    }
    writeln!(code, "        }}")?;
    writeln!(code, "    }}")?;
    writeln!(code)?;

    writeln!(code, "    pub const fn peripheral_index(self) -> u8 {{")?;
    writeln!(code, "        match self {{")?;
    for (peri, remap) in groups.keys() {
        let variant = format!("{}Remap{}", capitalize_peripheral(peri), remap);
        let index: String = peri.chars().filter(|c| c.is_ascii_digit()).collect();
        writeln!(code, "            UsartMapping::{variant} => {index},")?;
    }
    writeln!(code, "        }}")?;
    writeln!(code, "    }}")?;

    writeln!(code, "}}")?;

    generate_timer_mappings(&mut code)?;

    fs::write(out.join("generated.rs"), code)?;
    Ok(())
}

fn generate_timer_mappings(code: &mut String) -> Result<(), Box<dyn Error>> {
    const SIGNALS: &[(&str, &str)] = &[
        ("CH1", "ch1_pin"),
        ("CH2", "ch2_pin"),
        ("CH3", "ch3_pin"),
        ("CH4", "ch4_pin"),
        ("ETR", "etr_pin"),
        ("BKIN", "bkin_pin"),
        ("CH1N", "ch1n_pin"),
        ("CH2N", "ch2n_pin"),
        ("CH3N", "ch3n_pin"),
    ];

    for p in METADATA.peripherals {
        let Some(regs) = &p.registers else { continue };
        if regs.kind != "timer" {
            continue;
        }

        let mut remaps: BTreeSet<u8> = BTreeSet::new();
        for pin in p.pins {
            if let Some(r) = pin.remap {
                remaps.insert(r);
            }
        }
        if remaps.is_empty() {
            continue;
        }

        let enum_name = format!("{}Mapping", capitalize_peripheral(p.name));
        let timer_has_signal: BTreeSet<&str> = p.pins.iter().map(|pp| pp.signal).collect();

        writeln!(code)?;
        writeln!(code, "#[derive(Copy, Clone, Debug, PartialEq, Eq)]")?;
        writeln!(code, "#[repr(u8)]")?;
        writeln!(code, "#[allow(dead_code)]")?;
        writeln!(code, "pub enum {enum_name} {{")?;
        for r in &remaps {
            writeln!(code, "    Remap{r} = {r},")?;
        }
        writeln!(code, "}}")?;
        writeln!(code)?;

        writeln!(code, "impl {enum_name} {{")?;
        writeln!(code, "    #[inline(always)]")?;
        writeln!(
            code,
            "    pub const fn remap_value(self) -> u8 {{ self as u8 }}"
        )?;

        for (signal, method) in SIGNALS {
            if !timer_has_signal.contains(signal) {
                continue;
            }

            let pins_by_remap: Vec<(u8, Option<&str>)> = remaps
                .iter()
                .map(|r| {
                    let pin = p
                        .pins
                        .iter()
                        .find(|pp| pp.remap == Some(*r) && pp.signal == *signal)
                        .map(|pp| pp.pin);
                    (*r, pin)
                })
                .collect();

            // Accessor returns `Pin` directly if every remap exposes signal; else `Option<Pin>`.
            let always_exposed = pins_by_remap.iter().all(|(_, pin)| pin.is_some());

            writeln!(code)?;
            if always_exposed {
                writeln!(code, "    pub const fn {method}(self) -> Pin {{")?;
                writeln!(code, "        match self {{")?;
                for (r, pin) in &pins_by_remap {
                    let name = pin.expect("always_exposed checked above");
                    writeln!(code, "            {enum_name}::Remap{r} => Pin::{name},")?;
                }
            } else {
                writeln!(code, "    pub const fn {method}(self) -> Option<Pin> {{")?;
                writeln!(code, "        match self {{")?;
                for (r, pin) in &pins_by_remap {
                    let value = match pin {
                        Some(name) => format!("Some(Pin::{name})"),
                        None => "None".to_string(),
                    };
                    writeln!(code, "            {enum_name}::Remap{r} => {value},")?;
                }
            }
            writeln!(code, "        }}")?;
            writeln!(code, "    }}")?;
        }

        writeln!(code, "}}")?;
    }

    Ok(())
}

fn capitalize_peripheral(name: &str) -> String {
    let mut result = String::new();
    let mut capitalize_next = true;
    for c in name.chars() {
        if capitalize_next {
            result.push(c.to_ascii_uppercase());
            capitalize_next = false;
        } else {
            result.push(c.to_ascii_lowercase());
        }
    }
    result
}

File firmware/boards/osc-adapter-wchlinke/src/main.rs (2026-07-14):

#![no_std]
#![no_main]

use panic_halt as _;

osc_host_ch32::install_isrs!();

// The WCH IAP loader's APP-validity gate: word 0x12345678 at image offset
// 0x50 and 0x39373533 at 0x54 (loader disassembly, silicon-proven on this
// board). Those offsets are vector-table entries 20/21 -- the FLASH and RCC
// IRQs, which this firmware never enables -- so the loader's magic and the
// table share the space by WCH's own design. Absolute symbols override the
// device.x PROVIDEs; the cross-build CI step asserts the placement.
core::arch::global_asm!(
    ".global FLASH",
    ".set FLASH, 0x12345678",
    ".global RCC",
    ".set RCC, 0x39373533",
);

#[qingke_rt::entry]
fn main() -> ! {
    osc_host_ch32::runtime::run::run()
}

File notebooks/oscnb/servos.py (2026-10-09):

"""Servos under test.

One entry per physical servo. A servo is the motor, gearbox and pot: what is
being measured. The electronics doing the measuring live in boards.py.

Adding a servo is an entry here. The raw captures never change.

Keep DECLARED facts (geometry, travel, pot mapping) apart from MEASURED ones.
A measured value carries the notebook that produced it and its bracket, so a
number never loses its provenance by being copied into a constants file.
"""

from dataclasses import dataclass, field


@dataclass(frozen=True)
class Measured:
    """A value somebody measured, carried with its bracket and where it came
    from. Copied here so nobody has to hunt through memory, bringup docs and
    the mechanical package again - but a copy is only as good as its
    provenance, so `source` is mandatory and `note` carries the caveat that
    would otherwise be lost in the move.

    Never quote one of these without its bracket."""
    value: float
    lo: float
    hi: float
    unit: str
    source: str
    note: str = ""

    def __str__(self):
        s = f"{self.value:g} {self.unit} [{self.lo:g}, {self.hi:g}] ({self.source})"
        return s + (f" - {self.note}" if self.note else "")


@dataclass(frozen=True)
class Servo:
    key: str
    label: str
    model: str
    # pot mapping, three point anchored: pos = intercept + per_deg * degrees
    pos_intercept: float
    pos_per_deg: float
    # the envelope rungs are driven inside, in degrees
    travel_deg: tuple
    # seek guard band in pot counts, inboard of the physical stops
    guard_counts: tuple
    measured: dict = field(default_factory=dict)
    notes: str = ""

    def deg_to_pos(self, deg):
        return self.pos_intercept + self.pos_per_deg * deg

    def pos_to_deg(self, pos):
        return (pos - self.pos_intercept) / self.pos_per_deg

    @property
    def travel_counts(self) -> tuple:
        return tuple(self.deg_to_pos(d) for d in self.travel_deg)

    @property
    def runway_counts(self) -> float:
        lo, hi = self.travel_counts
        return hi - lo


SERVOS = {
    "sg90-a": Servo(
        key="sg90-a",
        label="SG90 clone, unit A",
        model="SG90",
        pos_intercept=232.0,
        # DISPUTED, but by less than it was. 19.96 is a three-point fit to
        # EYEBALLED horn angles (432=10, 2028=90, 3625=170 deg). The ripple
        # tach says 19.30, bracket [19.30, 19.43] across three independent 2S
        # sets, anchored on counted teeth and a confirmed 6/rev - see
        # measured["pot_scale_measured"]. The gap is 3.3%, down from the 9.1%
        # an earlier Welch-peak route claimed, which nb06 sec 5.5 showed was a
        # final speed divided by a mean speed. Kept at 19.96 only because the
        # intercept was fitted jointly with it and there is no absolute angle
        # reference to re-anchor the offset yet. Anything reported in DEGREES
        # or rad/s from this servo is ~3% out; counts and wiper-volts are
        # unaffected.
        pos_per_deg=19.96,
        travel_deg=(10.0, 170.0),
        guard_counts=(432, 3625),
        measured={
            # --- gear train, counted not fitted ---
            "gear_ratio_measured": Measured(
                234.73, 234.73, 234.73, ":1", "mechanical/sg90/measurements.py",
                "(47*38*32*23)/(10*10*8*7), counted teeth on the donor - exact"),
            "ripple_order_measured": Measured(
                6, 6, 6, "per motor rev", "bringup isns-diff runs 25-27",
                "3-segment commutator x 2 brushes; optical tach agreed 0.7% at "
                "d40 and 2.0% at d65 - a parts count, not an inference"),
            # --- bare-can motor model card, bringup run28 FINAL ---
            "kv_measured": Measured(
                7960, 7880, 8040, "RPM/V", "bringup isns-diff run28",
                "bare can, +/-1% HSI scale; pinion stayed on the shaft so true "
                "bare-shaft Kv sits slightly ABOVE this, call it ~8000"),
            "kt_measured": Measured(
                1.20, 1.19, 1.21, "mN-m/A", "bringup isns-diff run28", ""),
            "r_motor_measured": Measured(
                4.2, 4.16, 4.24, "Ohm", "bringup isns-diff run28",
                "bare can. nb03 got 4.5 [4.3, 4.8] in-servo via a full-duty "
                "onset anchor - the two are not the same measurement"),
            "l_motor_measured": Measured(
                0.5, 0.45, 0.55, "mH", "bringup isns-diff run28",
                "locked-rotor burst, tau_e 102 us"),
            "stall_current_measured": Measured(
                1.5, 1.45, 1.55, "A", "bringup isns-diff run28", "= V/R confirmed"),
            "stall_torque_measured": Measured(
                1.8, 1.75, 1.85, "mN-m", "bringup isns-diff run28", ""),
            "free_run_current_measured": Measured(
                0.081, 0.078, 0.084, "A", "bringup isns-diff run28", "at duty 65"),
            # --- in-servo, this dataset ---
            "r_winding_measured": Measured(
                3.77, 3.68, 3.92, "Ohm",
                "nb02 sec 21 route (i): locked-rotor ladder on 2S, rungs 15-24% "
                "only, 4 captures passing the span gate",
                "V0 +0.455 [0.409, 0.484] V from the same fit, terminal "
                "referenced. SUPERSEDES 3.91 [3.85, 3.99] with V0 +0.413, which "
                "was fitted 12-24%: the 12% rung is 144 ticks under the 160-tick "
                "floor, window_valid clear, and on a resistor the crest current "
                "sample reads 10% low there (nb02 sec 20). Correcting that rung "
                "by the resistor factor instead gives 4.23 with V0 +0.34, "
                "rejected because the corrected point sits 88 mV, 3 rms, off the "
                "honest line. R and V0 trade off across a 0.16 to 0.33 A span so "
                "the pair moves together; the 2% hump correction on the honest "
                "rungs alone gives 3.86. The free-shaft onset route read 4.23 "
                "through a coasting shaft"),
            "tau_e_measured": Measured(
                154, 140, 171, "us", "nb02 part 2, sample-to-sample pole",
                "loop time constant L/R_eff at a rung onset; 146 us on USB. "
                "An independent ARX fit on the same data gave 142 +/- 9. "
                "Unchanged by the crest floor of nb02 sec 20: the pole is a ratio "
                "of samples at one duty and one phase, so a per-duty under-read "
                "cancels"),
            "l_motor_in_servo_measured": Measured(
                0.62, 0.53, 0.74, "mH",
                "nb02 sec 21, tau x R_eff with the route (i) R",
                "bracket is the R_eff choice (3.79 to 4.34 Ohm) times the tau "
                "capture scatter; was 0.64 [0.55, 0.75] on the 12-24% R. "
                "l_motor_measured above is the bare can, a different unit"),
            "pot_scale_measured": Measured(
                19.30, 19.30, 19.43, "counts/deg",
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

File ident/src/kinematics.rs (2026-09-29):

//! Count <-> real-world-unit resolution for the calibration band. Turns the
//! endstop sweep (pos_min/max_phys, which equal the position table endpoints
//! raw_min/raw_max) plus the human-supplied travel angles into the on-servo
//! `CalibKinematics` values: angle endpoints in centi-degrees and the
//! physical gear ratio. Pure math; the caller writes the encoded values to
//! the three calib regs in a later commit.

use crate::ripple;

/// Encoded kinematics, ready for the three calib regs. All-zero is the
/// firmware's "unset" sentinel.
#[derive(Copy, Clone, Debug, PartialEq, Eq)]
pub struct KinematicsResult {
    pub angle_min_cdeg: i16,
    pub angle_max_cdeg: i16,
    pub gear_ratio_centi: u16,
}

/// Degrees of output travel per pot count over the phys span. 0.0 on a
/// zero/non-finite span.
pub fn deg_per_count(
    angle_min_cdeg: i16,
    angle_max_cdeg: i16,
    pos_min_phys: i32,
    pos_max_phys: i32,
) -> f64 {
    let count_span = pos_max_phys as f64 - pos_min_phys as f64;
    if count_span == 0.0 {
        return 0.0;
    }
    let angle_span_deg = (angle_max_cdeg as f64 - angle_min_cdeg as f64) / 100.0;
    angle_span_deg / count_span
}

/// Encode the human's angle at each phys end into centi-degree endpoints.
/// angle_at_min pairs with pos_min_phys, angle_at_max with pos_max_phys.
pub fn angle_endpoints(angle_at_min_deg: f64, angle_at_max_deg: f64) -> (i16, i16) {
    (
        cdeg_saturating(angle_at_min_deg),
        cdeg_saturating(angle_at_max_deg),
    )
}

/// Physical gear ratio (motor revs per output rev) x100, saturating to u16.
/// 0 on degenerate input (zero pot speed, zero/non-finite deg/count).
pub fn gear_ratio_centi(motor_rev_s: f64, pot_omega_cps: f64, deg_per_count: f64) -> u16 {
    if pot_omega_cps == 0.0 || deg_per_count == 0.0 || !deg_per_count.is_finite() {
        return 0;
    }
    // counts per full output rev closes ripple::gear_ratio_check's relative
    // ratio to the physical one (360 deg/rev)
    let counts_per_output_rev = 360.0 / deg_per_count;
    let ratio = ripple::gear_ratio_check(motor_rev_s, pot_omega_cps, counts_per_output_rev);
    let centi = (ratio.abs() * 100.0).round();
    if !centi.is_finite() {
        return 0;
    }
    centi.min(u16::MAX as f64) as u16
}

/// Total motor revs over a FULL rail-to-rail traverse, extrapolated from a
/// partial (soft-bounded) sweep via the per-count rate: anchor-free geometry,
/// so a run turning `motor_revs_run` over `pot_disp` counts scales to the whole
/// `count_span`. 0.0 when the sweep covered no counts or the span is non-finite.
pub fn full_span_motor_revs(motor_revs_run: f64, pot_disp: f64, count_span: f64) -> f64 {
    if pot_disp > 0.0 && count_span.is_finite() {
        motor_revs_run * count_span / pot_disp
    } else {
        0.0
    }
}

/// Output travel (deg) implied by a counted gear ratio and the full-traverse
/// motor revs: `motor_revs_full * 360 / gear_ratio`. The inverse of the
/// travel-anchored gear derivation. 0.0 on a zero/non-finite gear ratio.
pub fn travel_deg_from_gear(motor_revs_full: f64, gear_ratio: f64) -> f64 {
    if gear_ratio > 0.0 && gear_ratio.is_finite() {
        motor_revs_full * 360.0 / gear_ratio
    } else {
        0.0
    }
}

/// Assemble the three encoded values from the endstop sweep and the
/// human-supplied travel angles.
pub fn resolve(
    pos_min_phys: i32,
    pos_max_phys: i32,
    angle_at_min_deg: f64,
    angle_at_max_deg: f64,
    motor_rev_s: f64,
    pot_omega_cps: f64,
) -> KinematicsResult {
    let (angle_min_cdeg, angle_max_cdeg) = angle_endpoints(angle_at_min_deg, angle_at_max_deg);
    let dpc = deg_per_count(angle_min_cdeg, angle_max_cdeg, pos_min_phys, pos_max_phys);
    KinematicsResult {
        angle_min_cdeg,
        angle_max_cdeg,
        gear_ratio_centi: gear_ratio_centi(motor_rev_s, pot_omega_cps, dpc),
    }
}

fn cdeg_saturating(deg: f64) -> i16 {
    if !deg.is_finite() {
        return 0;
    }
    (deg * 100.0)
        .round()
        .clamp(i16::MIN as f64, i16::MAX as f64) as i16
}

#[cfg(test)]
mod tests {
    use super::*;

    #[test]
    fn endpoints_and_deg_per_count_round_trip() {
        // 190 deg of travel over a 3900-count phys span
        let (lo, hi) = angle_endpoints(0.0, 190.0);
        assert_eq!((lo, hi), (0, 19000));
        let dpc = deg_per_count(lo, hi, 100, 4000);
        assert!((dpc - 190.0 / 3900.0).abs() < 1e-12, "dpc {dpc}");
    }

    #[test]
    fn cdeg_rounds_and_saturates() {
        assert_eq!(cdeg_saturating(12.345), 1235);
        assert_eq!(cdeg_saturating(-12.345), -1235);
        assert_eq!(cdeg_saturating(400.0), i16::MAX);
        assert_eq!(cdeg_saturating(-400.0), i16::MIN);
        assert_eq!(cdeg_saturating(f64::NAN), 0);
    }

    #[test]
    fn deg_per_count_degenerate_span_is_zero() {
        assert_eq!(deg_per_count(0, 19000, 512, 512), 0.0);
    }

    #[test]
    fn gear_ratio_from_synthetic_inputs() {
        // dpc 0.05 deg/count, pot 4000 cps -> output 0.5556 rev/s;
        // motor 83.333 rev/s implies 150:1
        let g = gear_ratio_centi(83.333_333, 4000.0, 0.05);
        assert!((g as i32 - 15000).abs() <= 1, "gear {g}");
    }

    #[test]
    fn gear_ratio_degenerate_is_zero() {
        assert_eq!(gear_ratio_centi(83.0, 0.0, 0.05), 0);
        assert_eq!(gear_ratio_centi(83.0, 4000.0, 0.0), 0);
        assert_eq!(gear_ratio_centi(83.0, 4000.0, f64::NAN), 0);
    }

    #[test]
    fn gear_ratio_saturates_to_u16() {
        assert_eq!(gear_ratio_centi(1e9, 1.0, 0.05), u16::MAX);
    }

    #[test]
    fn travel_from_gear_round_trips_through_gear_ratio_centi() {
        // gear 150, motor_revs_full 79.1667 -> travel 190 deg over a 3900-count
        // span; feeding count_span as pot speed and travel/count_span as dpc
        // recovers the gear (gear_ratio_centi = motor_revs_full*360/travel).
        let motor_revs_full = 79.166_667;
        let gear = 150.0;
        let count_span = 3900.0;
        let travel = travel_deg_from_gear(motor_revs_full, gear);
        assert!((travel - 190.0).abs() < 1e-3, "travel {travel}");
        let dpc = travel / count_span;
        let g = gear_ratio_centi(motor_revs_full, count_span, dpc);
        assert!((g as f64 / 100.0 - gear).abs() < 0.02, "gear {g}");
    }

    #[test]
    fn full_span_scales_by_count_ratio() {
        // 20 motor revs over 1000 counts of a 4000-count span -> 80 full revs
        assert!((full_span_motor_revs(20.0, 1000.0, 4000.0) - 80.0).abs() < 1e-9);
    }
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

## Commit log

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2024-12-20 rework vias according updated constraints from jlc pcb
    [servo-dev-board.kicad_pcb]
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2025-01-01 Fixed error in PCB. Lowered isense resistor to 1.5k Ohm to increase max servo current to 1.5A
    [servo-dev-board.kicad_pcb, servo-dev-board.kicad_sch]
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2025-02-12 ensure adc sample values are correct
    [main.rs]
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2025-10-17 fix ADC voltage conversion using correct full-scale value
    Previously used PWM_MAX_DUTY (1799) instead of ADC_MAX_VALUE (4095)
    for ADC-to-voltage conversions, causing 2.28x overcurrent readings.
    Added ADC_MAX_VALUE constant and updated all ADC conversion functions.
    [main.rs]
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2025-11-27 fix sensor chip 3d rendering
    [encoder-board.kicad_pcb]
2025-11-28 Rename project from open-servo-controller to open-servo-core
    - Update project name in README.md with new structure and status
    - Update firmware directory path references in VSCode and Zed settings
    - Rename firmware directory to match new project name
    - Update KiCad library references in all hardware files
    - Fix package name in Cargo.toml
    - Update 3D model paths in footprints
    [encoder-board.kicad_sch, motor-mount.kicad_pcb, motor-mount.kicad_sch]
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2025-11-28 fix encoder board references
    [encoder-board.kicad_pcb]
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2025-12-10 update usb connector due to parts shortage
    [BOM-servo-dev-board.csv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]
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2025-12-17 Replace defmt with custom open-servo-log crate
    - Add open-servo-log: lightweight ufmt-based logging with compile-time
    level filtering, outputs to REPL via DebugIo trait
    - Enable build-std for smaller binaries, add ICF linker optimization
    - Consolidate toolchain config: add rust-toolchain.toml, remove
    board-specific .cargo/config.toml
    - Add Gain::inverse() to open-servo-math
    - Clean up unused code in safety module and PID controller
    [build.rs, main.rs]
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2025-12-21 redid the PCB after finding a bunch of issues
    [sg90-prod-ch32f006.kicad_pcb, sg90-prod-ch32f006.kicad_sch]
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2025-12-22 Various improvements.
    * Added pos low pass filter
    * Added `Duty` type to decouple pwm duty usage in core from boards
    * Used more conservative gains for servos
    * Fixed Max PWM on stm32 board (should be 3599 instead of 1799)
    * Updated DeciC to CentiC for better temperature calculations.
    * Added motor thermal monitor to avoid motor overheating
    [main.rs, units.rs]
2025-12-22 added NTC thermistor since CH32V006 doesn't have internal temp sensor
    [BOM-sg90-prod-ch32f006.csv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]
2025-12-22 fixed board naming error.
    [BOM-sg90-prod-ch32v006.csv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]
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2025-12-24 fix issues with build / defmt / cargo-embed. added servo engage / disengage command.
2025-12-24 Renamed torque to compliance, fixed engage setpoint, enhance REPL
    [units.rs]
2025-12-25 move setpoint to ServoCore, pass limits via ControlInput, add PidTunable trait; fix tests
    [units.rs]
2025-12-25 Added set_output_limits_auto_anti_windup() to PidI16 that re-derives integral clamps from output limits and immediately clamps the accumulator, then called it in fast_tick() before step() to fix inte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
2025-12-25 add CentiDeg32 (i32) and migrate core setpoint/error math off ad-hoc i32 alias
    [units.rs]
2025-12-25 Replace i16::abs() with saturating ops, apply cargo fmt
    - Use saturating_abs() and saturating arithmetic in ServoCore to
    eliminate i16 overflow hazards
    - Format all source files with cargo fmt
    - Add .claude to .gitignore
    - Add CLAUDE.md with project instructions
    [main.rs, units.rs]
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2025-12-25 Fix TIM2 slow tick to 100Hz, correct fault latching, and dedupe EVENT_QUEUE_SIZE
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2025-12-25 Time-base compliance blanking and position-error timeout, deriving fast-domain counters from board dt (fix 5ms→500ms bug)
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2025-12-25 Stage 9: Add build_medium_control_input() canonical builder
    Add pure function to merge MediumSnapshot sensor data (position,
    velocity, current_avg) with last_input metadata (setpoint, limits,
    bus_voltage) for medium tick processing.
    Replace manual ControlInput construction in control_medium_tick()
    with the new builder function.
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2025-12-25 Delete SafetyManager; delegate ticks to pipeline modules
    - Delete SafetyManager struct (~330 lines from safety/mod.rs)
    - Thin ServoCore to orchestrator pattern (delegates to fast/medium/slow)
    - Move FSM logic from mod.rs to medium.rs policy_medium()
    - Add pure functions to features/safety.rs and features/thermal.rs
    - Update ThermalModel.update_slow() to take dt_us parameter
    - Fix check_position to return Err on bad readings (was returning Ok)
    - Add CoreConfig accessor methods for app.rs compatibility
    - Update test_harness.rs to use new API
    - Migrate FSM tests to medium.rs (integration tests remain in mod.rs)
    All 94 tests pass. no_std check passes.
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2025-12-26 Add rounding helpers and new time/frequency units
    - Add div_round_{u32,i32} and mul_div_round_{i32,u32,i64,u64} helpers
    - Update unit conversions to use rounding: to_kelvin, as_rpm,
    to_percentage, scale_to, from_hw, to_mrad
    - Add MicroSecond and Hertz units with period conversion
    - Add tests for rounding behavior (sign-correct for signed types)
    - Fix defmt feature forwarding in open-servo-math
    - Rename mul_div_i32 -> mul_div_round_i32 in calibration.rs
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2025-12-27 Add MotorType, SensorCapabilities, and AdcResolution
    - MotorType: enum for motor topology (Bdc, Bldc)
    - SensorCapabilities: runtime bitflags for optional sensor detection
    - SensorCapability: enum for optional sensors only (invariant sensors always present)
    - MotorVoltage, MotorTemp, VsysVoltage, MotorEncoder
    - AdcResolution: enum for const generic calibration function parameters
    - Replaces compile-time feature flags with runtime capability checks
2025-12-27 Define simplified Board trait
    - Board trait with 4 methods: motor_type, sensor_capabilities, read_sensors, write_motor
    - Replaces 24+ fragmented traits with single cohesive interface
    - Board owns ADC DMA buffer internally (sidesteps const generic in trait)
    - Timing passed to kernel tick methods, not via trait
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2025-12-27 Add HostOp value-based ingress and strengthen kernel API
    - Add host_op.rs with FaultId, HostOp, HostResp, HostError, HostResult
    - Add ResetScope enum to reset.rs for deferred reset semantics
    - Add DebugReentrancyGuard helper (no atomics, Cell-based)
    - Add dt_us() and domain_seq() convenience methods to TickCtx
    - Add current_seq() to KernelCtx for per-domain sequence access
    - Replace KernelHost trait methods with single apply_op dispatch
    - Update device crate to use kernel-api host_op types
    - Implement Kernel and KernelHost traits for ServoKernel
    - Add Default impls for MotorCurrent and SensorFrame in hw crate
    - Fix DriveMode::Drive to not take DecayMode parameter
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2025-12-28 Fix static mutable access and add UART test crates
    - Use addr_of_mut! for static mutable access (Rust 2024 edition)
    - Add test-uart-stm32f301 and test-uart-ch32v003 test crates
    - Enable debug info in release profile for defmt
    [adc_config.rs, build.rs, main.rs]
2025-12-29 Add fault_mask support and kernel unit tests
    - Add fault_mask: u32 to KernelState for fault tracking
    - Wire fault gating in compute_gate_reason (returns Faulted if mask != 0)
    - Implement idempotent FaultAck/FaultAckAll via fault_bit() helper
    - Add 4 unit tests for commit_shadow and publish_telemetry
    - Fix commit_shadow to use phased approach (validate → read → apply → clear)
    to handle block-based dirty tracking correctly
    - Add ShadowStorage to STM32F301 board resources and ISR
    - Update ARCHITECTURE.md and test-uart crates
    [main.rs]
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2025-12-30 Add pre_init DBGMCU and UART RX pull-up for reliable SWD
    - Add pre_init to set DBGMCU before RAM init, ensuring SWD works during sleep
    - Add pull-up on PA10 (UART RX) to prevent noise when disconnected
    - Run cargo fmt
    [gpio.rs, main.rs]
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2026-01-02 Refactor board init to match proven sequence with typed PAC methods
    - RCC: Enable HSI first, then HSE, then PLL (safer startup sequence)
    - ADC: Configure DMA before ADC, use typed PAC methods
    - TIM: Use typed register field methods instead of raw bits
    - UART: Use typed methods for baudrate and config
    - Calibration: Fix NTC LUT alignment
2026-01-02 Use PidControllerI16 from open-servo-math for position control
    - Add open-servo-math dependency to kernel crate
    - Replace naive inline PID with PidControllerI16 (Q8.8 gains, anti-windup)
    - Use DerivativeMode::OnMeasurement to avoid setpoint kick
    - Fix PA11 alternate function (AF11 for TIM1_CH4, was AF6)
    - Add pull-down resistors on PWM pins for safe boot state
    - Add motor polarity reversal flag in pwm.rs
    - Enhance debug shell status with Engaged, Gate, Effort fields
    - Document Q8.8 gain format in board config (1280 = 5.0)
    [gpio.rs]
2026-01-02 Add Reading<T,R> type and expand debug shell with raw ADC values
    - Add Reading<T,R> enum (Valid/Invalid) with raw value tracking
    - Replace Sampled<T> with Option<Reading<T>> for optional sensors
    - Add MotorCurrentRaw/MotorVoltageRaw enums for BDC/BLDC support
    - Add vendor registers for raw ADC values and board capabilities
    - Expand debug shell status with raw values and board info
    - Add board capabilities to KernelConfig (ServoPosKind, MotorType)
    - Change position coordinate system to centered ±95° (-9500 to +9500)
    - Add test_support.rs for kernel test helpers
2026-01-02 Fix ADC trigger timing for current sensing
    Use Update event (CNT=0) instead of OC3REF (CNT=ARR-1) to trigger ADC
    at the center of the PWM ON pulse, where IPROPI is valid.
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2026-01-02 Add probe selection UI and fix macOS HID crash
    - Add probe dropdown selector in Flash panel
    - Enumerate probes in main() before event loop (macOS HID requirement)
    - Add refresh button to re-enumerate probes
    - Pass selected probe info to connection thread
    [main.rs]
2026-01-03 Remove async debug shell, use osctl for debugging
    - Delete debug_shell.rs from open-servo-services (~700 lines)
    - Simplify RTT to defmt (up 0) + rpc (up 1, down 0)
    - Remove shell_tick signal from board resources and ISR
    - Update osctl channel indices to match new layout
    - Delete Embed.toml (cargo-embed config, replaced by osctl)
    [main.rs]
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2026-01-04 Fix flash programming: keep HSI enabled per RM0313
    - Keep HSI oscillator on after PLL switch (flash programming requires it)
    - Use modify() for flash ACR to preserve prefetch buffer enable
    - Rewrite flash driver based on embassy-stm32 f1f3.rs pattern
    - Use modify() for CR register to avoid PAC re-locking bug
    - Add critical section around flash write operations
    - Clean up persist task and remove debug logging
    [main.rs]
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2026-01-05 Move Services bundle to services crate, add ServicePrimitives impl
    - Add bundle.rs with Services struct that owns PersistTask
    - Add Stm32Primitives impl of ServicePrimitives in firmware
    - Update firmware to use Services::run_once() loop pattern
    - Remove stub Services from runtime (kept as doc pointer)
    - Avoids circular dependency: services → runtime for ShadowStorage
    [main.rs]
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2026-01-10 Replace open-servo-shadow with embedded-shadow crate
    Delete internal shadow crate (~1000 lines) and use embedded-shadow.
    Merge facade translation into kernel's commit_shadow method.
    Create HostOps trait bridge in services for shadow access.
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2026-03-02 Ch32V006 based servo development board (#5)
    * fix kicad board template
    * scaffold kicad project for servo-dev-board-ch32v006
    * copy pasted sg90 prd ch32v006 schematics, and modify to fit. PCB should be about 85x65mm to accomodate TP ring rails for easy hardware testing.
    * add 0.1uF cap between motor terminals to reduce EMI
    * mostly done with ch32v006 based dev board schematics. Next is to pick footprint / parts and proceed to PCB design
    * wip
    * wip
    * completed board design
    * addressing review issues
    * wip
    * fixed battery connector pin outs. Added JLCPCB parts and produced production and gerber files
    * Remove excessive ground via arrays
    * routing ADC nets with higher priority so t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
    [COMMS.kicad_sch, DIAGNOSTICS.kicad_sch, MCU.kicad_sch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]
2026-03-03 Sg90 prod ch32v006 (#6)
    * update sg90-prod-ch32v006
    * rebuilt board
    * fix ch32v006 footprint. it should be smd instead of th
    * better debugger pogo pins placement and silk screen placement
    * delete jlcpcb plugin generated files
    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
    [BOM-sg90-prod-ch32v006.csv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]
2026-04-08 Revision V1B. Fixes:
    * Fixed reversed VDD/VCC on MCU.
    * Fixed TP silk screen labels on top row.
    * Updated RS1 to 10mOhm/333mW.
    * Updated System (green) LED resistor to 1.5kOhm to reduce brightness.
    * Aligned bottom row TPs to center of board.
    * Updated text on back silkscreen to reflect version / RS1 updates.
    [COMMS.kicad_sch, DIAGNOSTICS.kicad_sch, MCU.kicad_sch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]
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2026-04-29 final check and swapping ENCA/ENCB (#13)
    [MCU.kicad_sch, osc-dev-v006.kicad_pcb]
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2026-05-11 dxl-protocol: randomised variant fuzz + per-variant stuffing tests (#17)
    * dxl-protocol: add randomised variant fuzz and per-variant stuffing tests
    `round_trip_every_instruction` exercises one fixed example per Packet
    variant; none of those fixtures contain stuffing triggers, so a variant
    whose `decode()` arm accidentally used `Bytes::Raw` instead of
    `Bytes::stuffed()` would not surface there. Add two tests:
    - `round_trip_random_fields_across_variants` — deterministic PRNG sweeps
    all 16 variants with random ids/addresses/lengths/payloads (including
    occasional `0xFF 0xFF 0xFD` triggers), asserting write→parse→write
    yields byte-identical output.
    - `stuffing_round_trip_for_every_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
2026-05-20 pwm + adc + opa control path (#18)
    * add systick hal
    * add enable tim1
    * add tim1 hal for pwm motors
    * update ch32-metapac to latest git so we can have the latest OPA pac for v00x
    * add TIM1 pwm functions for center aligned pwm + peak / trough sampling scheme.
    * add OPA hal.
    * trim timer comments
    * modify timer hal so it is always using center aligned. Add channel enum for ergonomics.
    * add adc hal
    * add dma hal
    * add dma irq and adc buffer / shared statics
    * wire up hal init in board, and allow board firmware to configure board via board config.
    * make sure v006 uses correct arch json
    * wire-up the whole pwm -> opa -> adc -> dma -> kernel path.
    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
    [build.rs, main.rs]
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2026-07-13 firmware: osc-dev-v006 board images (#33)
    * firmware: land the osc-dev-v006 board images
    * ci: cross-build job + soft-arith gate (non-blocking, issue #32)
    [build.rs, main.rs]
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2026-07-14 osc-client: session, typed surface, backends, ENUM walk (#44)
    * host: fold unresolved ring bytes into terminal evidence
    * host: link-server mode for the sim engine
    * client: osc-client core -- pipe, session, typed client, errors
    * client: mgmt choreographies, fake + nusb backends, blocking facade, tests
    * host-ch32: note bench-verified 5v polarity
    * ci: client job
    [pins.rs]
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2026-07-14 transport: fleet-mute RCA -- cross-baud model, sec 8 pacing in set_baud (#48)
    * integration: cross-baud waveform reception model
    * integration: pin the parked-resolver mute
    * client: pace settles through the pipe, indeterminate baud writes
    * client: add mute characterization probe
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2026-07-14 bench: measure through the adapter, retire the pirate client (#50)
    * sim: gate pulse rescue declaration on held width
    * client: wire instrument module over the 0x6x records
    * bench: edge-to-stamp decoder over the adapter capture contract
    * host: instrument break-train + raw-baud verbs (0x66/0x67)
    * bench: swap transport onto the adapter instrument
    * bench: decode the measured capture contract (real break falls)
    * bench: settle-reprobe the walk, anchor the lying train, retune ping ceilings
    * bench: retire the pirate client
    [edges.rs]
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2026-07-15 client: edge capture survives host drain stalls (#54)
    * bench: dump failing cycles' stamp streams in the measure loops
    * adapter: snapshot rises before falls in the edge drain
    * client: unwrap capture ticks on one anchor chain, defer torn falls
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2026-07-25 hw: osc-dev-m007 and osc-sg90-m007 board designs (#56)
    * hardware: osc-dev-m007 wip - m007/led/fet library parts, power block schematic
    * hardware: ts-1088r + ts3425ba tact switches in shared lib
    * hw: design osc-dev-m007 schematics
    * hw: design osc-sg90-m007 schematics and pcb
    * hw: design osc-dev-m007 pcb
    * hw: add osc-sg90-m007 renders to readme
    * hw: swap dev-m007 parts to in-stock equivalents
    [bridge.kicad_sch, bus.kicad_sch, halfbridge.kicad_sch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]
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2026-08-03 hw: encoder-board 3v3 redesign, kicad 10 resave, lcsc field cleanup (#58)
    [encoder-board.kicad_pcb, encoder-board.kicad_sch]
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2026-09-02 mech: cad tooling, stenciljig, carrier scaffold, encbench rework (#68)
    * mech: m10 donor facts, pot ear pockets, gear2 bore warning
    * mech: blueprint svg, live preview and blender render tooling
    * mech: stenciljig package with qa suite
    * mech: tier-2 carrier scaffold
    * mech: readme entries for carrier and stenciljig
    * mech: encbench first-light rework
    * gitignore: generated board bom outputs
    * sim: iterate handles in deliver_garble, clippy needless_range_loop
    * core: slice-iterate profile slot words in ceiling test, clippy
2026-09-03 fw: raw device-counts ABI, ntc removal, bare-opa current sense (#69)
    * docs: protocol sec 5.5 raw device-counts unit convention
    * core: raw-counts sensor frame, delete unit conversion layer
    * servo-ch32: fix AnalogChannel::pin to v006 silicon adc map
    * core: calib sense/winding blocks, counts-domain telemetry regions
    * servo-ch32: delete ntc and vbus sensing
    * servo-ch32: hal opa bare mode for external feedback network
    * servo-ch32: bare-opa current sense from wiring, boot bias, arm-b profile
    * servo-ch32: fix stale remap8 and rm-section comments
    * servo-ch32: drop bare prefix from opa types
    * core: drop raw_ prefix from telemetry raw block fields
    * core: rename RawFrame to SensorF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
    [osc-servo.json]
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2026-09-07 core: undervolt default is a brown-out floor, not a 2s battery line
2026-09-07 osc: rail-gate widen parks the tau trip; e5 stalls open the gates too
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2026-09-08 adapter: crash record, exception reset, independent watchdog (#84)
    * host: adapter diagnostics tail on the info record
    * adapter: crash record, exception reset, independent watchdog
    [build.rs, main.rs]
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2026-09-10 notebooks: chain-3 datasets on the 24 MHz ADC, board and servo constants split (#95)
    * notebooks: usb campaign recaptured on the hacked chain, notebook 00 re-executed
    * notebooks: bridge, stepcoast and ripple campaigns recaptured on the hacked chain
    * notebooks: breakaway and reversal campaigns recaptured on the hacked chain
    * notebooks: re-execute bridge, bemf, friction and inertia on the hacked chain
    * notebooks: re-execute gear train on the hacked chain, position adc caveat
    * notebooks: 2s campaigns on the 24 mhz adc with per-duty windows
    * notebooks: usb campaigns on the 24 mhz adc with per-duty windows
    * notebooks: split rig constants into board and servo registries
    * notebooks: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
    [servos.py]
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2026-09-14 osc: sweep static-load skips every seek for a resistor in place of the motor (#97)
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2026-09-14 notebooks: 01 04 05 carry the crest floor, friction and inertia re-fitted on corrected current (#102)
2026-09-14 core: velocity from the back-emf boxcar, the pot observer keeps position, disturbance and rest (#101)
    * core: model-bemf velocity on a 1 ms boxcar
    * core: velocity loop reads the back-emf, the pot observer keeps rest, stall and thermal
    * core: current-loop feedforward from the trajectory reference
    * core: delete the fusion blend gain
    * docs: velocity comes from the back-emf, the pot observer keeps position and disturbance
    * core: seed the pot observer gains as board defaults
    * osc: inertia step length as a flag
    [osc-servo.json]
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2026-09-23 sim: seeded fleet calibration is SAVEd so reboot keeps it and FACTORY wipes it like hardware (#117)
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2026-09-28 host: adapter reports uptime and resets since power-on (#130)
    [main.rs]
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2026-09-28 notebooks: mg90-a low stop moved to 232 after the stall (#135)
    [servos.py]
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2026-09-28 osc: data state on every command and recover resets a corrupt servo (#147)
    [main.rs]
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2026-09-29 ident: fake servo keeps the bus latency and the kernel's stall verdict (#189)
2026-09-29 ident: bench fixture runs at the servo's speed, inertia aborts on the soft limits (#191)
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2026-09-29 ident: burst winding fit resolves the pwm waveform and screens its captures (#196)
    [burst-0.csv, burst-1.csv, burst-10.csv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]
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2026-10-01 docs: calibrate again from time to time and after a hard stall (#229)
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2026-10-02 ident: an envelope that never bends sizes no burst rung (#240)
    * ident: an envelope that never bends sizes no burst rung
    * ident: a burst too short for halves says so, not that they disagreed
    [burst-0.csv, burst-1.csv, burst-2.csv]
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2026-10-02 ident: a burst promotes only from two duties and a bent envelope (#242)
    * ident: an envelope that outlasts its levels sizes no burst rung
    * ident: a burst at one duty promotes no winding
    [burst-0.csv, burst-1.csv, burst-2.csv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]
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2026-10-05 firmware: swap the terminal taps with the drive direction (#271)
    * firmware: swap the terminal taps with the drive direction
    * firmware: map the terminal taps with a plain match on the drive direction
    [main.rs]
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2026-10-06 ident: say which r the held burst route plans from, or why it is skipped (#281)
    * ident: say which r the held burst route plans from, or why it is skipped
    * ident: pin the jam check leaving a rail toward mid travel
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2026-10-06 transport: test the own id first and skip the foreign check on a classified frame (#287)
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2026-10-07 transport: stamp breaks by dma from tim3 for the drift tracker (#303)
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2026-10-08 notebooks: apply the triage (#319)
    * notebooks: retire 00 and fold capture integrity into 10
    * notebooks: retire 07 and fold the rest-noise method into 08
    * notebooks: retire 14 and fold the burst R-V0 ridge into 02
    * notebooks: 17 cut the absolute-R thermometer section
    * notebooks: 18 state where the shipped thermal constants come from
    * notebooks: strip board-D history and test the gear-slip candidate in 12
    * notebooks: 05 note that ident inertia ships the current-decay route
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2026-10-09 drivers: gate the cal trim loop on a seeded ruler-noise simulation (#329)
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2026-10-10 client: queue enough usb in transfers to ride a 100 ms stall (#340)
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2026-10-15 ident: probe the jam check with short pulses each way (#422)
    * ident: model breakaway, lash, a dead pot and an open motor in the test servo
    * ident: add gear classes and the stall-or-sag current sensor
    * ident: probe the drive direction with short pulses each way
    * ident: pin the jam check over the start, rail and breakaway sweep
    * osc: run every jam check on the pulse probe
    * ident: drop the centring's out-and-back nudge
    * osc: take the jam check's gear class from the servo
    * ident: fix the jam check's dead-pot, host-stall and stop verdicts
    * ident: judge jam-check rests and creeps across the converter carry
    * ident: discount each carry's measured skipped codes from jam-check trave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
2026-10-15 budget: book openloop drive on its own rows (#426)
    * budget: book openloop drive on the closed rows
    * bench: give up the openloop sweep on a stalled shaft
    * budget: book openloop drive on its own rows
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
